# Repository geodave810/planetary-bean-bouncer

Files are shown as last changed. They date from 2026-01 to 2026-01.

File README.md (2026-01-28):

# Planetary Bean Bouncer

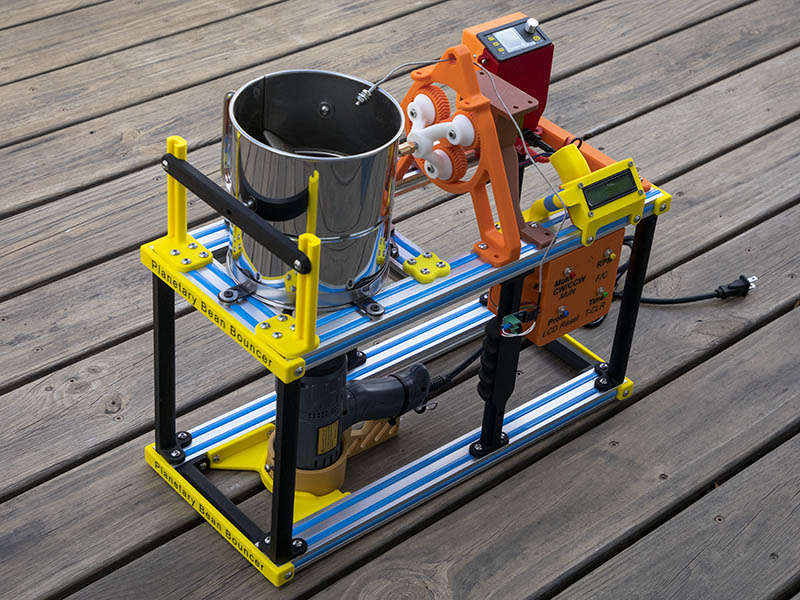
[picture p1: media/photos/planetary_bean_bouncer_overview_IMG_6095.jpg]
Planetary Bean Bouncer overview


Open-source DIY coffee roaster project based on an 8-cup flour sifter with a
stationary heat gun and a rotating agitator, controlled by Arduino-based firmware.

> ⚠️ **Safety notice:** This project involves high heat, mains power, and moving
mechanical parts. Read `DISCLAIMER.md` before building or operating.

## Overview

The Planetary Bean Bouncer is a small-batch coffee roaster that uses a modified
flour sifter to agitate coffee beans while heat is applied from a fixed-position
heat gun. The design focuses on simplicity, accessibility, and repeatability
using commonly available components.

This repository contains the firmware, 3D-printable parts, and reference
documentation needed to build and experiment with the roaster.

## Features
- Rotating agitator driven by a stepper motor
- Stationary heat gun (no linear motion in this design)
- Arduino-based controller
- Button and LCD user interface
- Temperature sensing support (thermocouple or thermistor, depending on build)
- Configurable parameters in firmware (speed, timing, alerts)

## Project status

This project is in active development. Documentation is currently minimal
and will be expanded over time as the design evolves.

## Repository layout
- `firmware/` — Arduino firmware (MIT License)
- `hardware/` — STL files and hardware reference images (CC BY-NC 4.0)
- `wiring/` — Basic UI wiring reference (Fritzing)
- `media/` — Photos and videos

## Fit & Tolerance Test Prints

Two optional test STLs are included to verify printer tolerances before printing any main parts:

- **hardware/STL/accessories/Test_1.stl** – Verifies screw, nut, bearing, and lever-lock electrical terminal fits.
- **hardware/STL/accessories/Gearing_5_1_16_24_64_Test_Rev36.stl** – A reduced-size planetary gear set using the same tolerances as the full gearbox, intended to check gear mesh and rotation (also works as a fidget).

Highly recommended if your printer or filament is untested.

See `docs/tolerance-test-prints.md` for details.

## Quick start
1. Review `hardware/README.md` for printed parts and notes
2. Review `wiring/README.md` for the basic UI wiring reference
3. Install the Arduino IDE
4. Open the firmware sketch in `firmware/`
5. Configure pins and parameters at the top of the sketch as needed
6. Upload to the Arduino and test without heat before roasting

## Hardware overview
- Controller: Arduino Uno (or compatible)
- Stepper driver: DRV8825, TMC2209, or similar (builder’s choice)
- Motor: NEMA 17 stepper motor
- Sensor: Thermocouple module (e.g., MAX6675) or thermistor
- Heat source: Consumer heat gun (stationary)

> Motor and driver wiring is intentionally not prescribed, as there are many
valid configurations depending on hardware choices.

For builders interested in fabricating their own wobble disc rather than purchasing one, a detailed fabrication guide that inspired this approach is available here:

https://library.sweetmarias.com/wp-content/uploads/2024/09/Wobble-Disc-Coffee-Roaster-3-red-tubes-model-build-instructions.pdf

## Licensing

This project uses multiple licenses:

- **Firmware:** MIT License  
- **Hardware design files (STL, images, diagrams):**
  Creative Commons Attribution-NonCommercial 4.0 (CC BY-NC 4.0)

This allows free personal and educational use while preventing unauthorized
commercial exploitation of the hardware design.

## Support this project ☕

This project is released as open source and free to use.

If you find it useful and would like to support continued development,
documentation, and future improvements, you can:

☕ **Buy me a coffee:** https://buymeacoffee.com/geodave

Support is entirely optional, but always appreciated.

## Credits

Project design and implementation: **David Bunch**  
Firmware was developed with AI-assisted code generation and subsequently
reviewed, tested, and maintained by the author.

Some components are derived from existing open-source designs and are credited
in the relevant subdirectories.

## Build log and videos

This project has been developed and documented over time through both
videos and a long-running build log.

### YouTube playlist
A playlist documenting the design, prototyping, testing, and iterations
of the Planetary Bean Bouncer:

https://www.youtube.com/playlist?list=PLyy5iFdDEfauqgzqg_eptvup8FIkFzkNk

New videos will be added as the project continues to evolve.

### Build log
A detailed build log and discussion thread dating back to September 2025,
including design decisions, experiments, and lessons learned:

https://forum.v1e.com/t/diy-coffee-roaster/51195

These resources provide additional context beyond what is captured
in the repository files.

## Build guide

A step-by-step mechanical build guide is available in the `docs/` directory.
This guide covers frame construction, drive components, and flour sifter
integration.

Electronics integration will be documented separately.

## FAQ

Common questions about build difficulty, food safety, and project scope are answered here:

➡️ [docs/FAQ.md](docs/FAQ.md)

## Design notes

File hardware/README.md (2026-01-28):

# Hardware Design Files

This directory contains hardware design files for the
**Planetary Bean Bouncer Coffee Roaster**, including STL files,
reference images, and diagrams.

## Licensing

The hardware design files in this directory are licensed under:

**Creative Commons Attribution–NonCommercial 4.0 International (CC BY-NC 4.0)**  
https://creativecommons.org/licenses/by-nc/4.0/

This license allows free personal and educational use of the hardware
design while preventing unauthorized commercial exploitation.

> Note: Firmware in this repository is licensed separately under the
> MIT License. See the top-level LICENSE files for details.

## Commercial use

If you are interested in using this hardware design for commercial
purposes (kits, products, or resale), please contact the author to
discuss licensing options.

Reasonable commercial licensing helps support continued development
of this project.

## Credits and Attribution

### Planetary Gear System

The planetary gear system used in this project is based on the following
open-source design:

- **Planetary Gear Set** by *Emmett Lalish*  
- Source: https://www.thingiverse.com/thing:53451  
- License: As specified by the original author on Thingiverse

The original design has been modified for this project, including
changes to dimensions, tolerances, and integration with the
Planetary Bean Bouncer assembly.

All original licensing terms of the upstream design are respected.

See /docs/tolerance-test-prints.md for optional test prints.

## Bill of Materials (BOM)

A bill of materials is provided in the `BOM/` directory as an Excel
spreadsheet:

- `Planetary_Bean_Bouncer_BOM.xlsx`

The BOM reflects the author’s current build and may include specific
part selections or suppliers. Equivalent components may be substituted
based on availability.

The BOM and other documentation in this directory are licensed under
CC BY-NC 4.0 unless otherwise noted.

## Cost and sourcing notes

The estimated total cost for the author’s build is approximately **$234 USD**.
This reflects the specific parts used and prices at the time of purchase.

Many builders may already have some components on hand (such as fasteners,
electronics, or motors), which can significantly reduce the total cost.

Several parts may also be substituted or fabricated by the builder. For example:
- The wobble disc can be machined or cut from suitable material instead of
  being purchased as a finished part.
- Equivalent motors, drivers, and fasteners may be used depending on availability.

As with most DIY projects, actual cost will vary based on sourcing,
substitutions, and existing inventory.

### Fabricating Your Own Wobble Disc

For builders interested in fabricating their own wobble disc rather than purchasing one, a detailed fabrication guide that inspired this approach is available here:

- **Wobble Disc Fabrication Guide**  
  https://library.sweetmarias.com/wp-content/uploads/2024/09/Wobble-Disc-Coffee-Roaster-3-red-tubes-model-build-instructions.pdf

This guide includes:
- Measurements
- Recommended materials
- Assembly considerations

Using this reference, builders can reduce part cost and customize the wobble disc to their own preferences. Always ensure proper balance and clearances when fabricating your own part.

For build history and videos, see the main README.

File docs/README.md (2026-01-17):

# Documentation

This directory contains documentation for the Planetary Bean Bouncer project.

## Available guides

- **Mechanical Build Guide**  
  Located in `build-guide/`  
  Covers frame construction, drive components, and flour sifter integration.

Electronics wiring and configuration are not yet documented and will be
addressed in a future update.

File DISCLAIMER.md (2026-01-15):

# Disclaimer

This project is provided for **educational and experimental purposes only**.

Building and operating a DIY coffee roaster involves inherent risks, including
but not limited to:

- High temperatures and risk of burns or fire
- Use of mains-powered electrical equipment
- Moving mechanical components and pinch points
- Smoke, fumes, and the need for adequate ventilation

## Responsibility

You are solely responsible for:

- The safe design, construction, wiring, and operation of your build
- Selecting materials and components appropriate for heat and food-contact use
- Compliance with applicable electrical codes, safety standards, and local laws
- Supervising the device during operation (do not leave unattended)

The author does not guarantee the safety, performance, or suitability of any
design, instructions, or files provided in this repository.

## No warranty

All files, designs, and documentation are provided **“as is”**, without warranty
of any kind, express or implied.

See the applicable license files for additional terms and limitations.

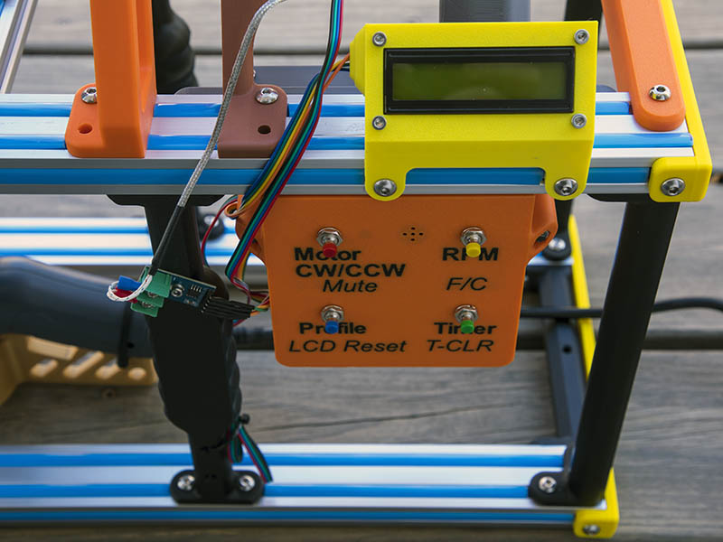
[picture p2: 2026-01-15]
media/photos/controller_closeup_IMG_6003.jpg

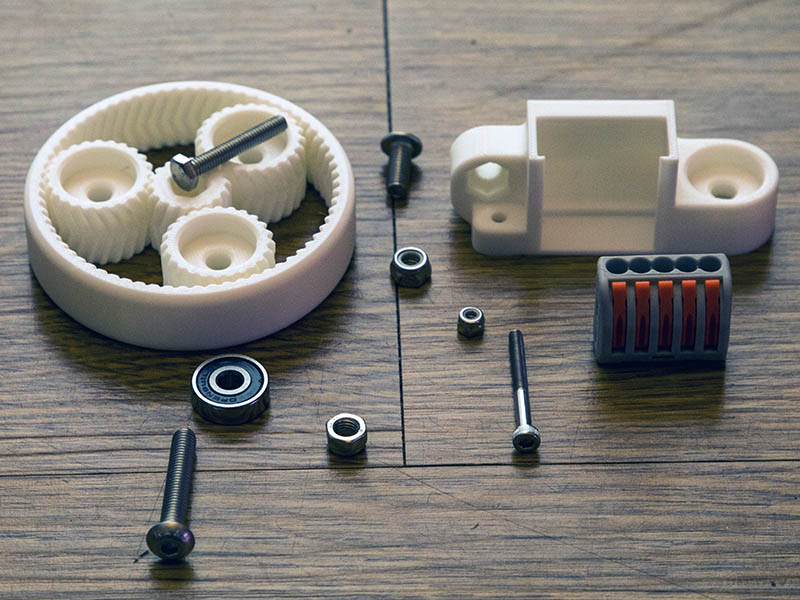
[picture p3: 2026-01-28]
media/photos/IMG_6096_800x600.jpg

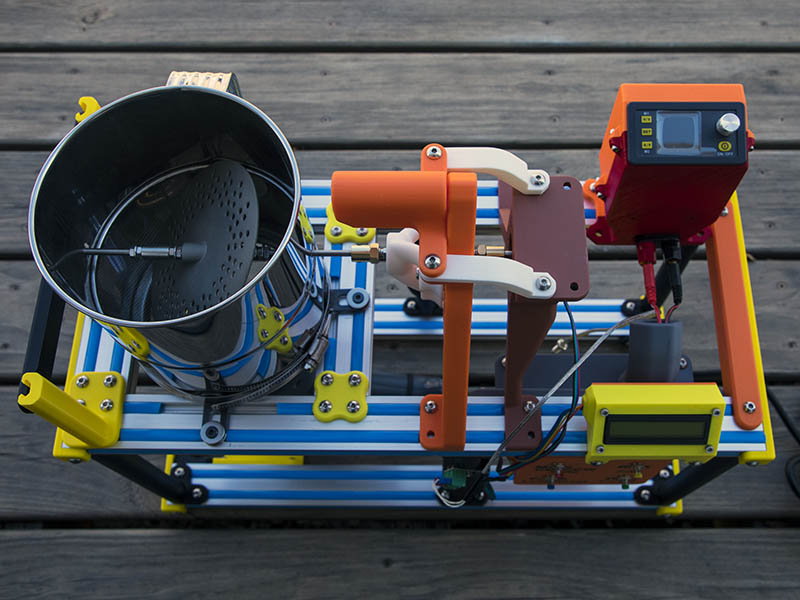
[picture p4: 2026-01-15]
media/photos/overall_top_IMG_6002.jpg

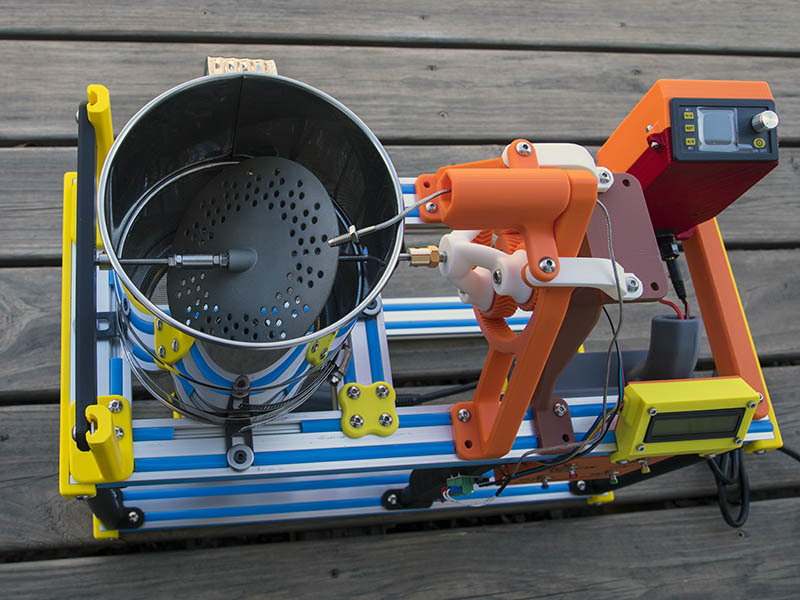
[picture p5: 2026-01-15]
media/photos/agitator_detail_IMG_6001.jpg

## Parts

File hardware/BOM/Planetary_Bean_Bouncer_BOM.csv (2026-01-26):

Planetary Bean Bouncer BOM | QTY | Item | Notes | Optional / Fabrication Notes | Unit Price | Extended Price | Link
 | 1 | Heat Gun |  |  | $28.99 | $28.99 | https://www.amazon.com/dp/B07DX4PL1M?ref=ppx_yo2ov_dt_b_fed_asin_title
 | 1 | 8 Cup SS Flour Sifter |  |  | $23.99 | $23.99 | https://www.amazon.com/dp/B0DD3ZB6MT?th=1
 | 4 | 2040 V-Groove 500mm (You could also use T-Slot) |  |  | $10.08 | $40.32 | https://www.zyltech.com/2040-v-groove-extrusion-pre-cut-lengths-300mm-2000mm/
 | 1 | 2040 V-Groove 300mm (You could also use T-Slot) |  |  | $6.95 | $6.95 | https://www.zyltech.com/2040-v-groove-extrusion-pre-cut-lengths-300mm-2000mm/
 | 1 | Flexible Rubber Extrusion Strips (10 meters) | Keeps most of Chaff from roasting out of extrusions |  | $11.95 | $11.95 | https://www.zyltech.com/flexible-rubber-extrusion-strips-for-20mm-aluminum-extrustion-black-blue-or-white/
 | 1 | 5"-7" SS Band Clamp |  |  | $3.99 | $3.99 | I bought mine from ACE hardware, too expensive from Amazon
 | 1 | 24 - 18x18x30 L Brackets (4 needed) |  |  | $7.99 | $7.99 | https://www.amazon.com/dp/B09G9GKFPT?th=1
 | 1 | M5 fender washers (pack of 50) only 12 needed |  |  | $7.99 | $7.99 | https://www.amazon.com/dp/B0CLK7J4NB?th=1
 | 4 | M3x25mm (LCD Case) |  |  | $0.12 | $0.48 | https://boltdepot.com/Product-Details?product=15291
 | 8 | M3x10mm (Arduino Mount and Motor Mount) |  |  | $0.08 | $0.64 | https://boltdepot.com/Product-Details?product=7220
 | 8 | M3 Locknuts (Not needed on Motor Mount) |  |  | $0.07 | $0.56 | https://boltdepot.com/Product-Details?product=4792
 | 1 | M5x12mm screws about 72 needed (Pack of 100) |  |  | $8.60 | $8.60 | https://boltdepot.com/Product-Details?product=6633
 | 1 | M5 Tee Nuts about 72 needed(Pack of 100) |  |  | $7.95 | $7.95 | https://www.amazon.com/Kangsiyu-Aluminum-Profile-Printer-Accessory/dp/B0FQ3P1GF3/141-9617972-1494545
 | 3 | M5x35mm screws (Planets to Planet carrier) |  |  | $0.32 | $0.96 | https://boltdepot.com/Product-Details?product=6638
 | 1 | 625-2RS bearings (12 pack) (planet bearings only 7 needed) |  | 1 bearing end of shaft rides on. | $8.99 | $8.99 | https://www.amazon.com/%EF%BC%BB12-Pack%EF%BC%BD625-2RS-Ball-Bearings-Miniature/dp/B0BRQP2QG7?th=1
 | 3 | M5 washers (planet bearings) | The washers I used were precision washers |  | $0.05 | $0.15 | https://boltdepot.com/Product-Details?product=4515
 |  |  | from openbuilds if you can find them
 | 8 | M5 locknuts |  |  | $0.09 | $0.72 | https://boltdepot.com/Product-Details?product=4794
 | 3 | M5x50mm screws for controller case |  |  | $0.56 | $1.68 | https://boltdepot.com/Product-Details?product=6641
Electrical Parts |  |  |  |  |  |  |  | Parts for optional 3D printed wobble disc |  |  |  |  |  |  | Parts for optional 3D printed wobble disc |  |  |  |  |  |  | Parts for optional 3D printed wobble disc |  |  |  |  |  |  | Parts for optional 3D printed wobble disc |  |  |  |  |  |  | Parts for optional 3D printed wobble disc |  |  |  |  |  |  | Parts for optional 3D printed wobble disc |  |  |  |  |  |  | Parts for optional 3D printed wobble disc
 | QTY | Item | Notes |  | Unit Price | Extended Price | Link |  | QTY | Item | Notes | Unit Price | Extended Price | Link |  | QTY | Item | Notes | Unit Price | Extended Price | Link |  | QTY | Item | Notes | Unit Price | Extended Price | Link |  | QTY | Item | Notes | Unit Price | Extended Price | Link |  | QTY | Item | Notes | Unit Price | Extended Price | Link |  | QTY | Item | Notes | Unit Price | Extended Price | Link |  | QTY | Item | Notes
 | 1 | 1602 LCD Display with Backpack | I did not purchase this one, but should work as well as what I bought | If you want solid electrical connections, you should be familiar | $8.99 | $8.99 | https://www.amazon.com/dp/B0D2L9SK1P?th=1
 | 1 | 0.9 Step Angle Nema 17 Stepper Motor 1.5 A |  | with soldering and solder some of these connections. | $12.95 | $12.95 | https://www.zyltech.com/high-accuracy-0-9-step-angle-nema-17-stepper-motor-1-5-a-0-42-nm-59-ozin/
 | 1 | MAX6675 Thermocouple | I did not purchase this one, but should work as well as what I bought | So you will need some extra supplies here | $7.69 | $7.69 | https://www.amazon.com/HiLetgo-MAX6675-Thermocouple-Temperature-Arduino/dp/B01HT871SO?th=1
 | 1 | Arduino Uno + CNC shield + DRV8825 | I did not purchase this one, but should work as well as what I bought |  | $18.99 | $18.99 | https://www.amazon.com/DAOKI-Expansion-Arduino-Heatsink-Engraving/dp/B08KFYKKN4
 | 1 | 12V Power Supply 5A 60W | I did not purchase this one, but should work as well as what I bought |  | $11.89 | $11.89 | https://www.amazon.com/ALITOVE-100-240V-Transfomer-Converter-5-5x2-5mm/dp/B0F1N4J7R2?th=1
Parts for optional 3D printed wobble disc
 | QTY | Item | Notes |  | Unit Price | Extended Price | Link
 | 1 | 3D printed 316L Wobble Disc |  | See Sweet Maria?s wobble disc fabrication guide (link in README). | $55 | $55.00 | Best price I found was from https://app.prototi.com/quote
 | 1 | 4 Pcs M5x200mm 304 SS Threaded Rod (only 1 needed) |  |  | $7.99 | $7.99 | https://www.amazon.com/dp/B09LGXG6F1?th=1
 | 2 | M5 External tooth SS washers |  |  | $0.06 | $0.12 | https://boltdepot.com/Product-Details?product=7121
 | 4 | M5 serrated flange nuts SS |  |  | $0.22 | $0.88 | https://boltdepot.com/Product-Details?product=12008
 | 4 | M5 Hex Nuts (Use 4mm wide nuts, NOT narrow jam nut) | Narrow jam nuts make it more difficult to get wrench on |  | $0.07 | $0.28 | https://boltdepot.com/Product-Details?product=4775
 |  |  | both nuts
 | 1 | M5x18mm long SS spacers | Not completely necessary but covers more of threaded rod |  | $9.69 | $9.69 | https://www.amazon.com/dp/B0F8QPGNJL?
 | 1 | 10 pack of 5mm Bore shaft lock collars SS (only 1 needed) | These do not have to be SS since they are outside sifter |  | $7.88 | $7.88 | https://www.amazon.com/dp/B0F5TFX6PL?th=1
 | 1 | 5mm bore motor hex coupler, M4 threads on opposite side | Connects Motor to Sun gear and planets to main shaft |  | $7.99 | $7.99 | https://www.amazon.com/dp/B08M379TCT?th=1
 | 2 | M4 x25mm SS tap bolts | These connect planetary gear to M4 bore of hex couple on |  | $0.19 | $0.38 | https://boltdepot.com/Product-Details?product=5940
 |  |  | each side of the gear.
 |  |  | you might want to get a couple of 20mm & 30mm length
 |  |  | in case those lengths work better for you.
 | 2 | M4 Locknut SS |  |  | $0.08 | $0.16 | https://boltdepot.com/Product-Details?product=4793
 | 2 | M4 Lock washers SS |  |  | $0.07 | $0.14 | https://boltdepot.com/Product-Details?product=4811
 |  | Estimated total (author?s build): |  |  |  | $313.92
 |  | Prices are approximate and reflect the author?s build at the time of writing.
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

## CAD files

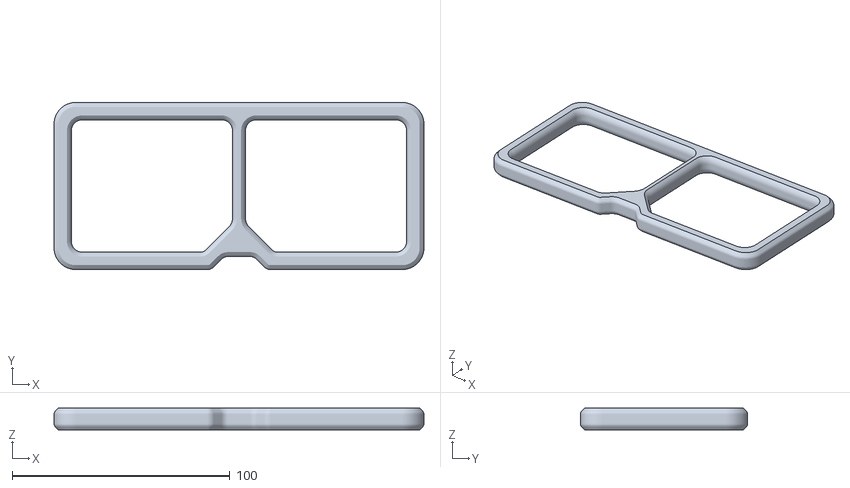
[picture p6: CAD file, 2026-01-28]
hardware/STL/accessories/Bearing_Height_Shim.stl
170.0 x 76.8 x 10.0

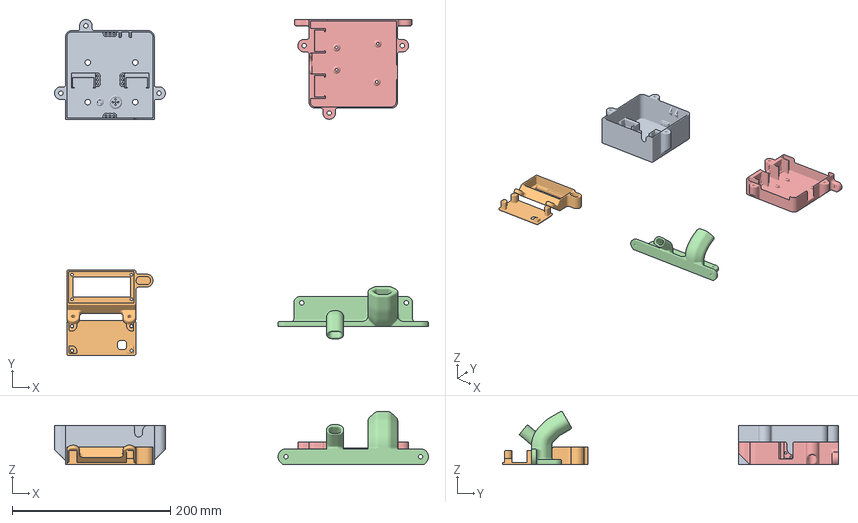
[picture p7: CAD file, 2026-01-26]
hardware/STL/electronics/ArduioUnoMount_Rev4.3mf
472.2 x 424.2 x 67.3 mm
ArduioUnoTopMount_Rev4.stl_1
LCD1602_MinCase.stl
Text
ShortV_Connect_V3.stl
ArduioUnoBaseMount_Rev4_1.stl

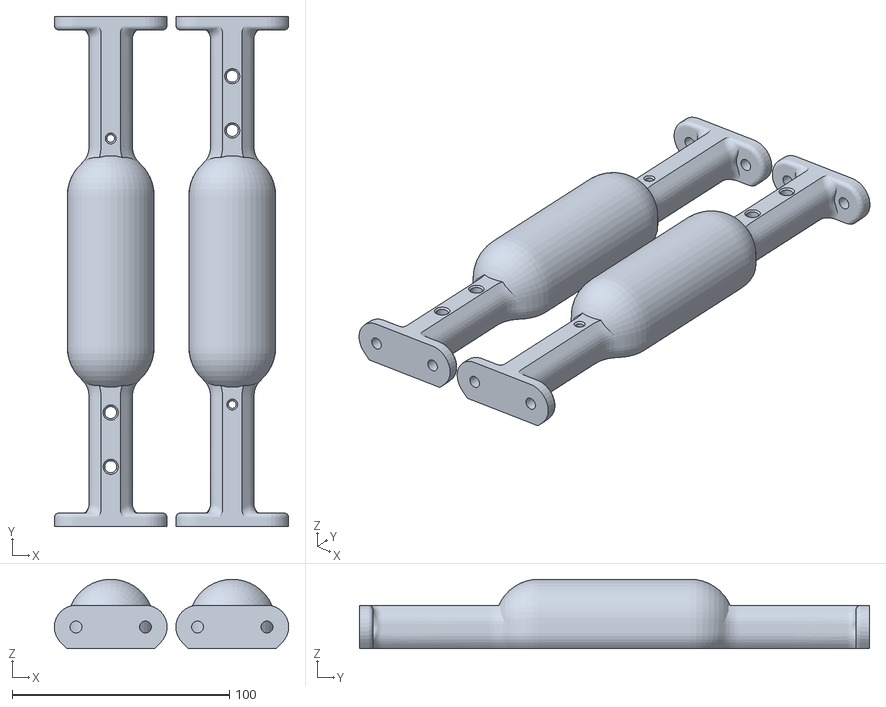
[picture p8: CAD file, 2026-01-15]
hardware/STL/frame/CenterColumns.stl
108.0 x 235.0 x 32.0

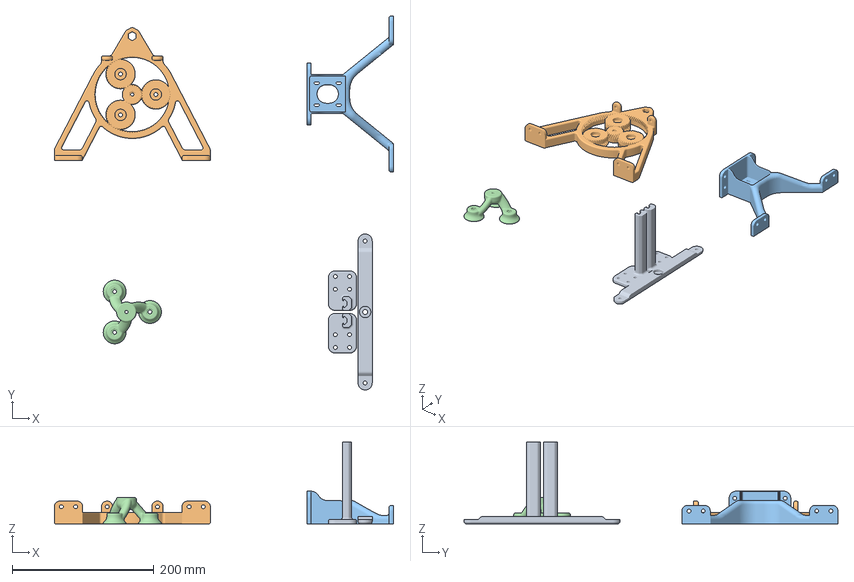
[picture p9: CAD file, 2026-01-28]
hardware/STL/gearing/PlanetaryBeanBouncerDriveTrain.3mf
478.5 x 527.2 x 115.0 mm
BearingColumns.stl
FlourPlanetGears_5_1_24_36_96_Rev35.stl
Nema17_Medium_Mount.stl
PlanetDrive_5_1_Rev35.stl

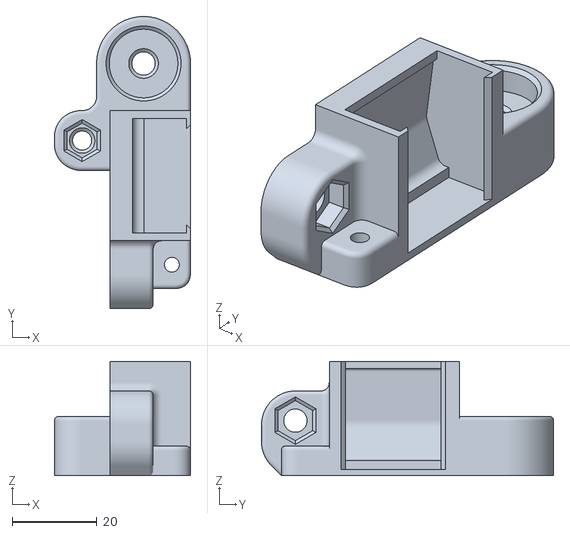
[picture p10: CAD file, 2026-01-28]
hardware/STL/accessories/Test_1.stl
32.1 x 69.0 x 27.0

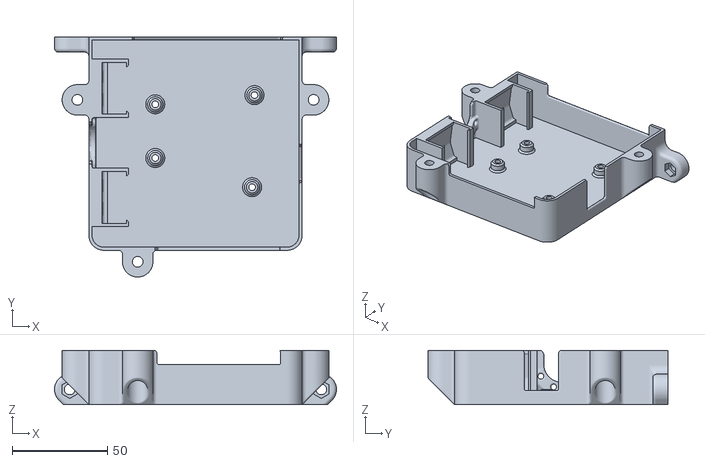
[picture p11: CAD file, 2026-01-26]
hardware/STL/electronics/ArduioUnoBaseMount_Rev4_1.stl
148.0 x 126.0 x 28.5

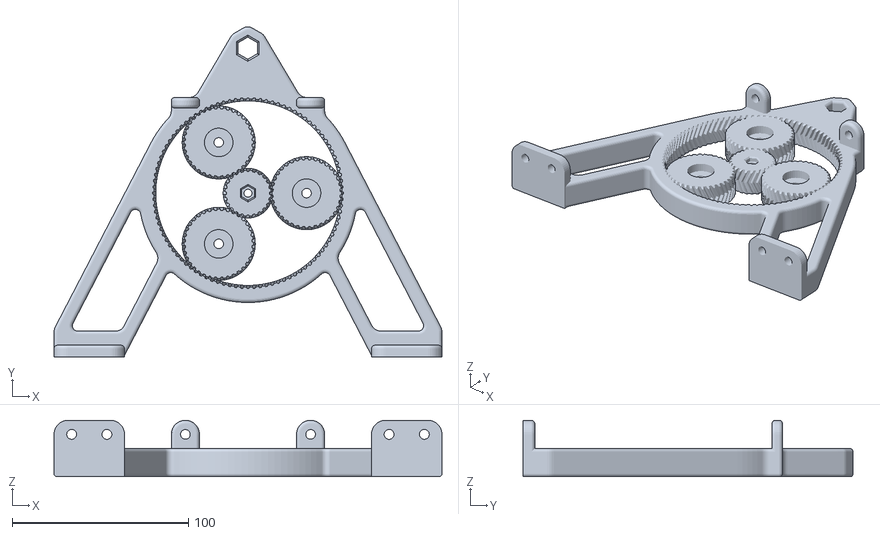
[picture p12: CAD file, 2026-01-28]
hardware/STL/gearing/FlourPlanetGears_5_1_24_36_96_Rev35.stl
220.0 x 187.3 x 32.0

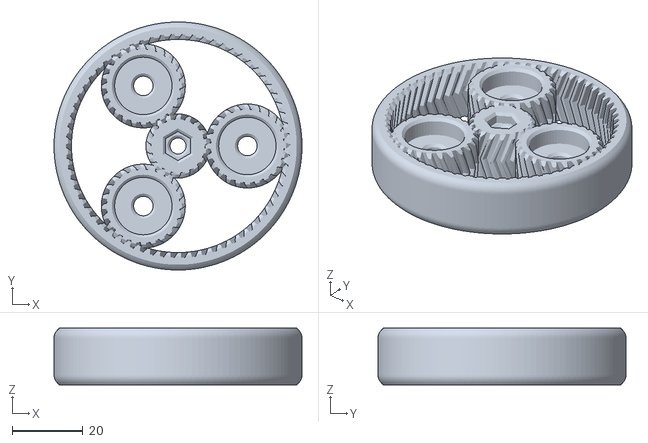
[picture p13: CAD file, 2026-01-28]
hardware/STL/accessories/Gearing_5_1_16_24_64_Test_Rev36.stl
70.0 x 70.0 x 16.0

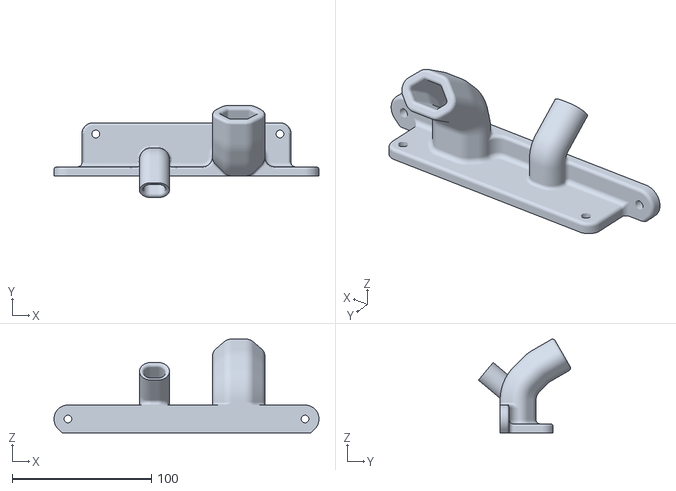
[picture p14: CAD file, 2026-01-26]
hardware/STL/electronics/ShortV_Connect_V3.stl
190.0 x 66.1 x 67.3

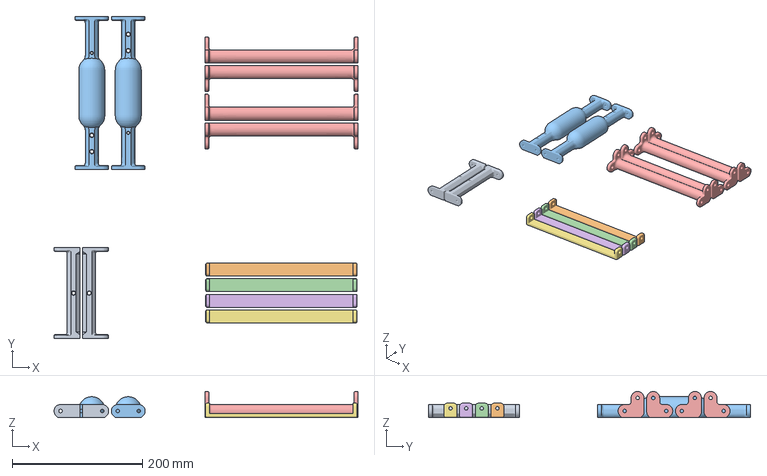
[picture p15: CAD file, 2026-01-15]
hardware/STL/frame/AluminumFrame_Parts.3mf
466.7 x 494.7 x 39.9 mm
Assembly x 7

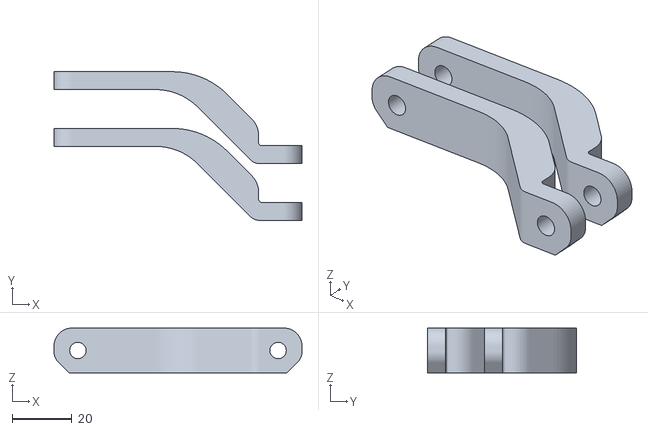
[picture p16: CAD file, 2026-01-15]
hardware/STL/gearing/Motor_TieBraces.stl
83.0 x 49.8 x 15.0

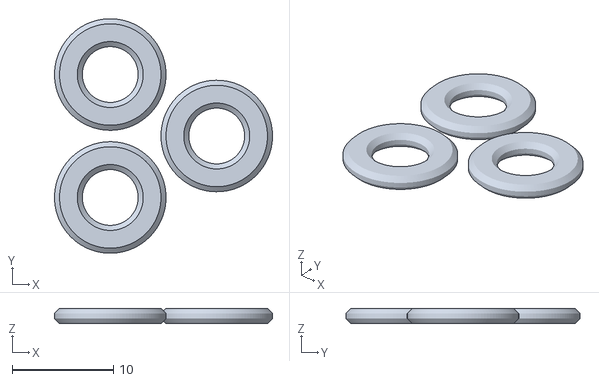
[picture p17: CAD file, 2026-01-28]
hardware/STL/accessories/M5_Bearing_Shims.stl
21.5 x 23.1 x 1.50

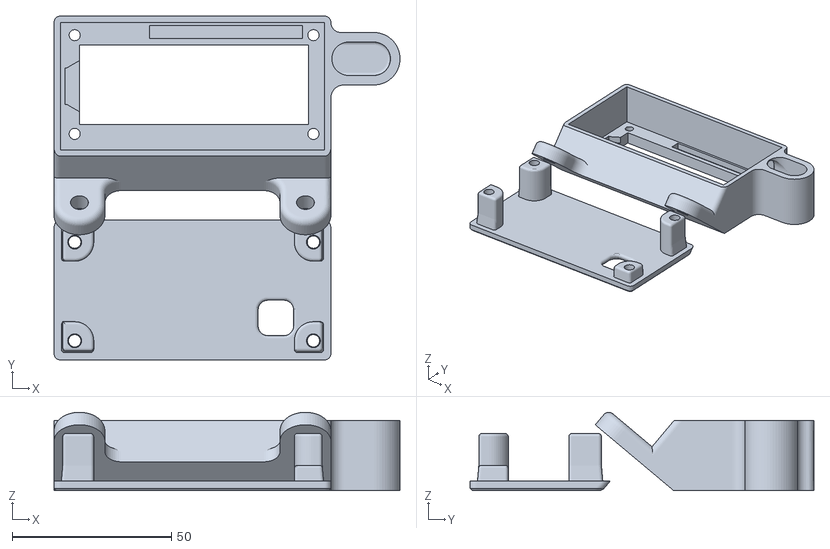
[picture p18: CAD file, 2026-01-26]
hardware/STL/electronics/LCD1602_MinCase.stl
108.7 x 108.0 x 24.7

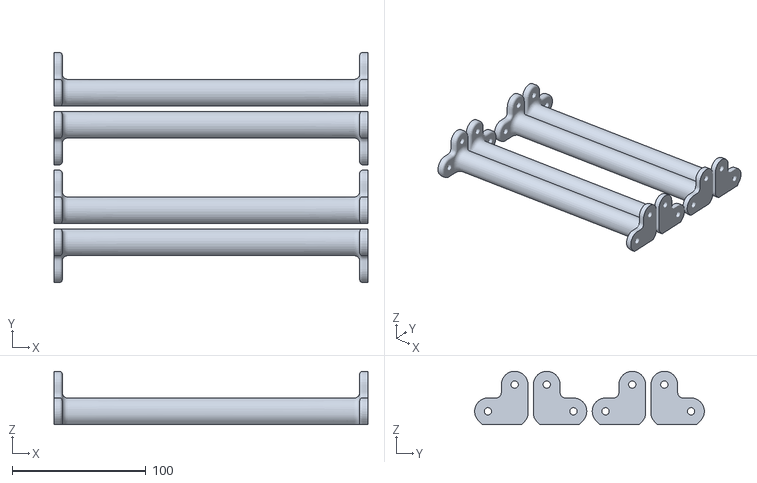
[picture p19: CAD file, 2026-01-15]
hardware/STL/frame/2020_CornerColumns.stl
235.0 x 172.0 x 39.9

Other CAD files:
hardware/STL/gearing/BearingColumns.stl
hardware/STL/accessories/HexAdapter_Height_Shim.stl
hardware/STL/electronics/HeatGunStand_42mm.stl
hardware/STL/gearing/Nema17_Medium_Mount.stl
hardware/STL/accessories/3D_Print_WobbleDisc_JambNuts.step
hardware/STL/accessories/ShaftCoupler_M5x20mm_M5x20mm_rev18.stl
hardware/STL/accessories/SifterDrillTemplate.stl
hardware/STL/accessories/SilfterOutsideDrillGuide.stl
hardware/STL/electronics/ArduioUnoTopMount_Rev4.stl
hardware/STL/frame/2020x140_Mod.stl
hardware/STL/frame/2020x2040_FarEndPlate.stl
hardware/STL/frame/2040_Bot_Connects.stl
hardware/STL/frame/2040x2040_End_Plates.stl
hardware/STL/frame/Endcap_2040s.3mf
hardware/STL/frame/Heatgun_Center_V2.stl
hardware/STL/gearing/PlanetDrive_5_1_Rev35.stl
hardware/STL/gearing/SensorChannel.stl

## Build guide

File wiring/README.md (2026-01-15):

# Wiring reference

This directory contains a simplified wiring reference for the
Planetary Bean Bouncer controller user interface.

## Included files

- `Planetary_Bean_Bouncer_UI.fzz`  
  Fritzing project file showing the breadboard layout.

- `Planetary_Bean_Bouncer_UI_bb.png`  
  PNG export of the breadboard view for easy viewing without Fritzing.

## Scope

The wiring diagram illustrates the following components:
- Arduino Uno
- LCD (I2C)
- Buttons
- Status LEDs
- Buzzer

Stepper motor and driver wiring is intentionally omitted, as there are
many valid configurations depending on the hardware used.

## Notes

Resistor values shown are typical; exact values are not critical.

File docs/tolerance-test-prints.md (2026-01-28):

# Fit & Tolerance Test Prints

These test prints are provided to validate printer accuracy, filament behavior, and hardware fit before printing the main Planetary Bean Bouncer parts.

## When to Use These
- New printer or newly tuned printer
- New filament brand or material
- If previous prints showed tight fits, binding, or gear noise

---

## Test_1.stl – Hardware Fit Test

**Purpose:**  
Validates all commonly used hardware fits in this project.

**Covers:**
- Screw and nut sizes used throughout the build
- Bearing fits
- Lever-lock electrical terminal fit

**How to Evaluate:**
- Screws should insert without excessive force
- Nuts should press in firmly without cracking
- Bearings should be snug but removable by hand
- Lever-lock terminal should slide in without distortion

If fits are too tight or loose, adjust:
- Horizontal expansion
- Flow rate
- Extrusion multiplier

---

## Gearing_5_1_16_24_64_Test_Rev36.stl – Planetary Gear Test

**Purpose:**  
A compact planetary gear set using the same tolerances as the full gearbox.

**Notes:**
- Functionally equivalent tolerances to the full-size gear system
- Can be assembled and rotated by hand
- Small enough for quick test prints
- Also doubles as a fidget after printing

**Pass Criteria:**
- Gears rotate smoothly by hand
- No binding or tooth fusion
- Minimal backlash consistent with printed gears

---

## Recommended Print Settings
(Use the same settings intended for the final parts)

- Layer height: ___
- Nozzle size: ___
- Material: ___
- Perimeters: ___

---

## If Tests Fail
- Do **not** force assemblies
- Adjust tolerances or slicer settings
- Reprint tests before printing final parts

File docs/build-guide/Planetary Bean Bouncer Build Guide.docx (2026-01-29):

Planetary Bean Bouncer – Mechanical Build Guide

Before you begin:

- Review the full guide once before assembling.

- Print Test_1.stl to verify hole tolerances for screws, nuts, and bearings.

- Print Gearing_5_1_16_24_64_Test_Rev36.stl to test planetary gear meshing (can be used as a fidget after printing).

- Verify you have all hardware listed in the BOM.

- Do not fully tighten fasteners until shaft alignment is confirmed.

This guide documents the mechanical assembly of the Planetary Bean Bouncer coffee roaster. Electronics wiring and configuration are not covered in this document and will be addressed in a separate guide.

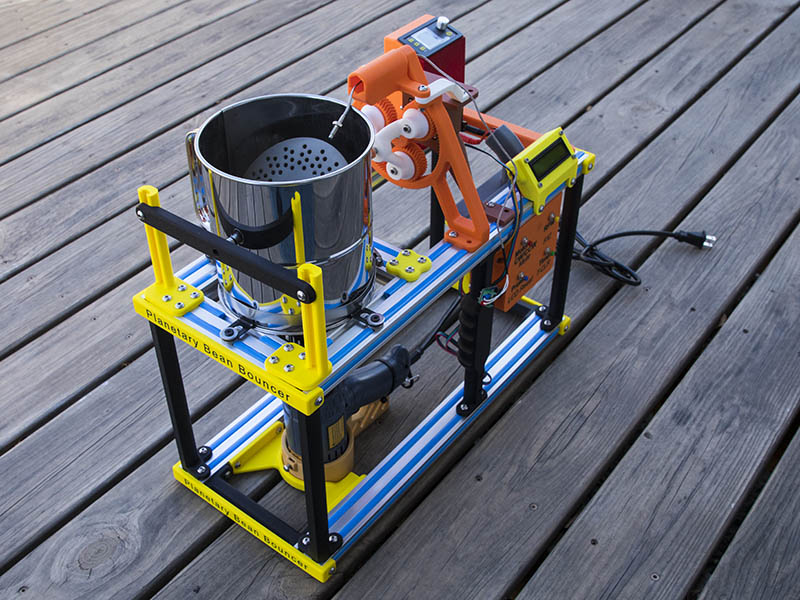
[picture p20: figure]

Frame

The aluminum extrusion part of the frame consists of 4-2040x500mm and 2-2040x140mm V-Slot extrusion. You should also be able to substitute T-Slot 2040 if you prefer, but I have not tested those. I am using 74 Tee Nuts and all the 3D printed parts are sized to use M5x12mm screws. I use 18-8 stainless steel button head screws as I prefer them. Anything outside the sifter does not need to be stainless though. You might have less or more of these Tee Nuts depending on how you configure it. For instance, you will probably power the 12 V supply for the motor differently than I do or you might not want to bother with the planetary gear system.

We will start with building the bottom frame. For the bottom frame we start by assembling V2040_Bot_Connect_1 (1st part of 2040_Bot_Connects.stl) and the Heatgun_Center_V2 3D prints. If you are using a different heat gun than in BOM, this probably will not work for you. The Heat gun center part is not necessary but makes it easy to line up the heat gun if you are using the same heat gun I have listed in BOM. You need 4-M5x12mm screws with Tee Nuts for the Heat gun center part and 2-M5x12mm screws with Tee Nuts for the V2040_Bot_Connect_1

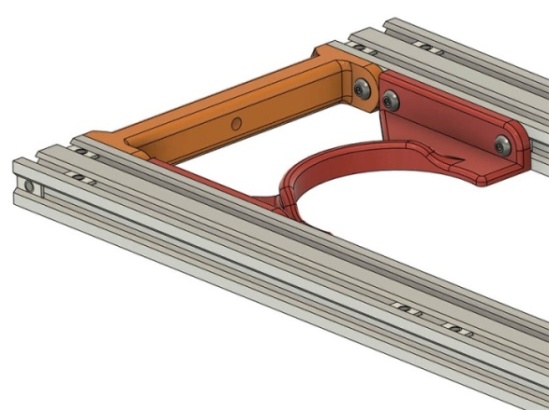
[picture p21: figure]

Connect V2040_Bot_Connect_2 (2nd part of 2040_Bot_Connects.stl) at each end of the frame with 2-M5x12mm screws and Tee Nuts like the other end.

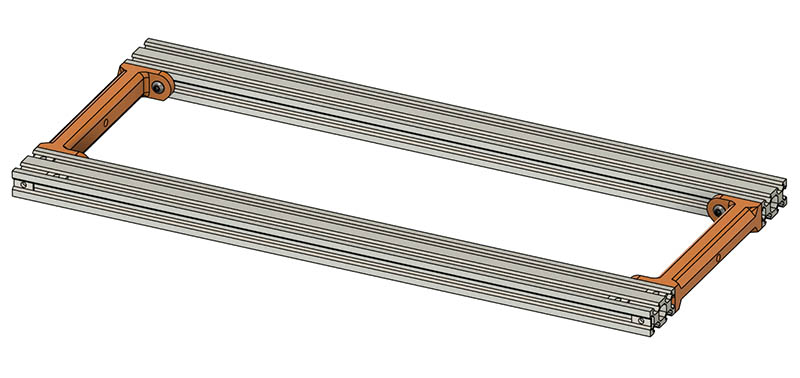
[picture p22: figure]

Add V2020_Column_1 (1st part of 2020_CornerColumns.stl) to the front corner below where sifter will be using 2-M5x12mm screws. These columns are slightly different because of print orientation, but essentially any of the 4 can go in any corner.

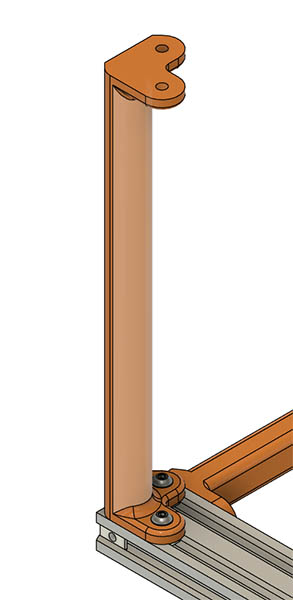
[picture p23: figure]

Add V2020_Column_2 (2nd part of 2020_CornerColumns.stl) to opposite short side using 2-M5x12mm screws.

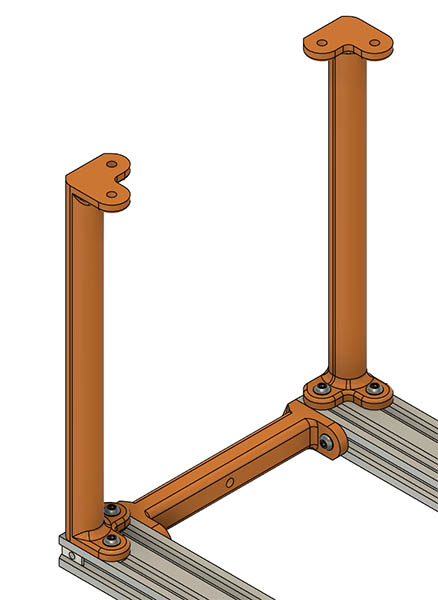
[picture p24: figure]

Do the same for the opposite side using 4-M5x12mm screws.

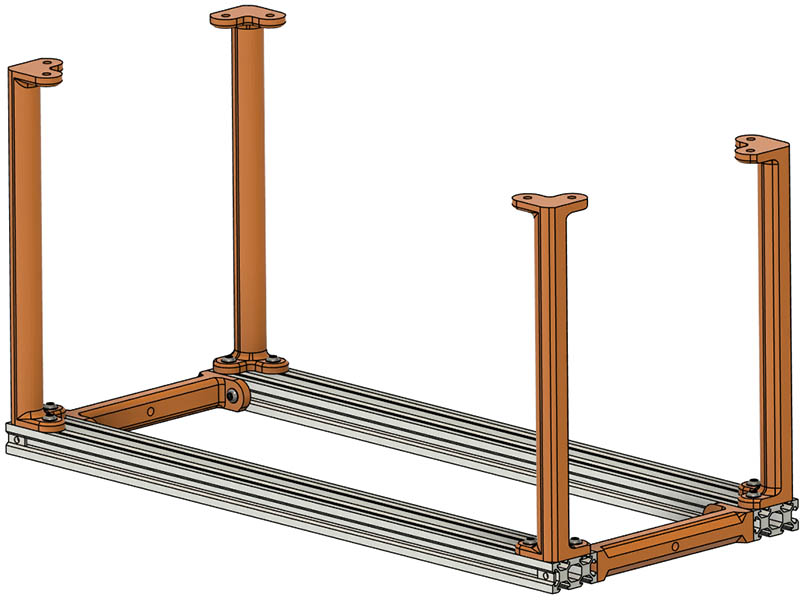
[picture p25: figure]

Assemble CenterColumn_1.stl and CenterColumn_2.stl to the bottom frame using a total of 4-M5x12mm screws as shown. They do not necessarily have to go in the middle. I have the back one in the middle for grabbing the center to dump roasted beans, but the front one I have closer to electronics to fasten MAX6675 and wire tie motor wire.

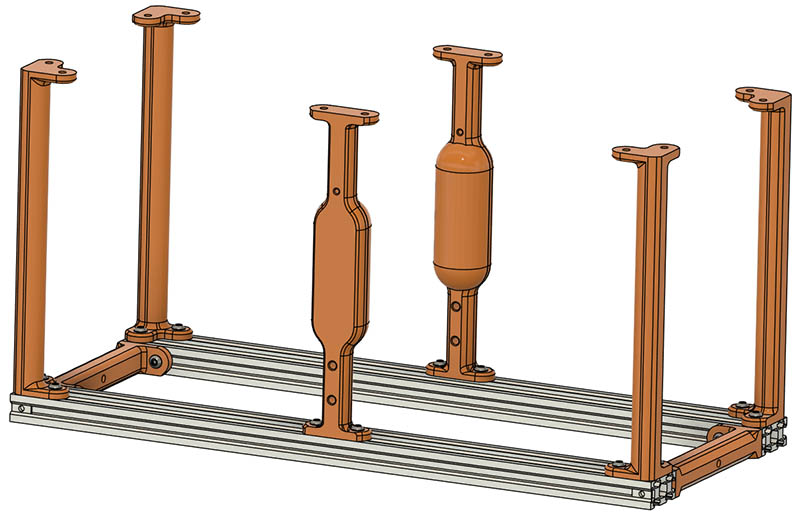
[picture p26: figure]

Turn the bottom frame upside down and assemble the 2-2040x500mm lengths to it using 12-M5x12mm screws with a Tee Nut for each screw.

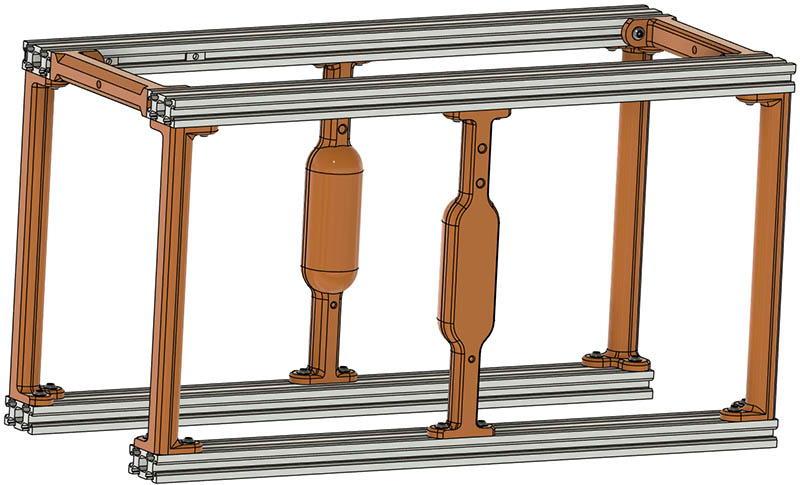
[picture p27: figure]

Turn frame right side up again and add 10 Tee Nuts as shown in green to the 2–2040x140mm length extrusions. They do not need to be positioned correctly yet.

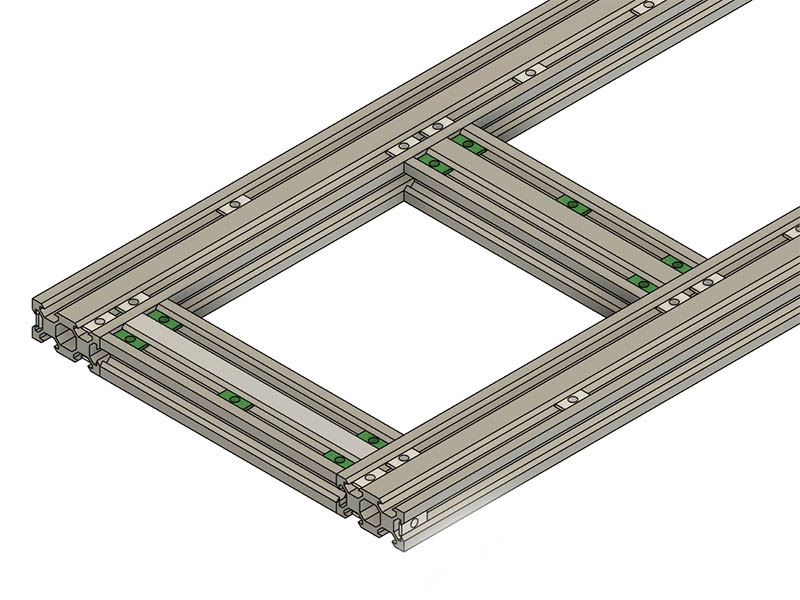
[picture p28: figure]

Attach Bearing_Column_1.stl and Bearing_Column_2.stl (from BearingColumns.stl ) to the end of the 2040x500mm top frames and the short 2040x140mm extrusion as shown. Make sure you have a Tee Nut as shown in the middle of short 2040. It does not have to be centered yet. Use 8-M5x12mm screws with Tee Nuts in the extrusions to connect these.

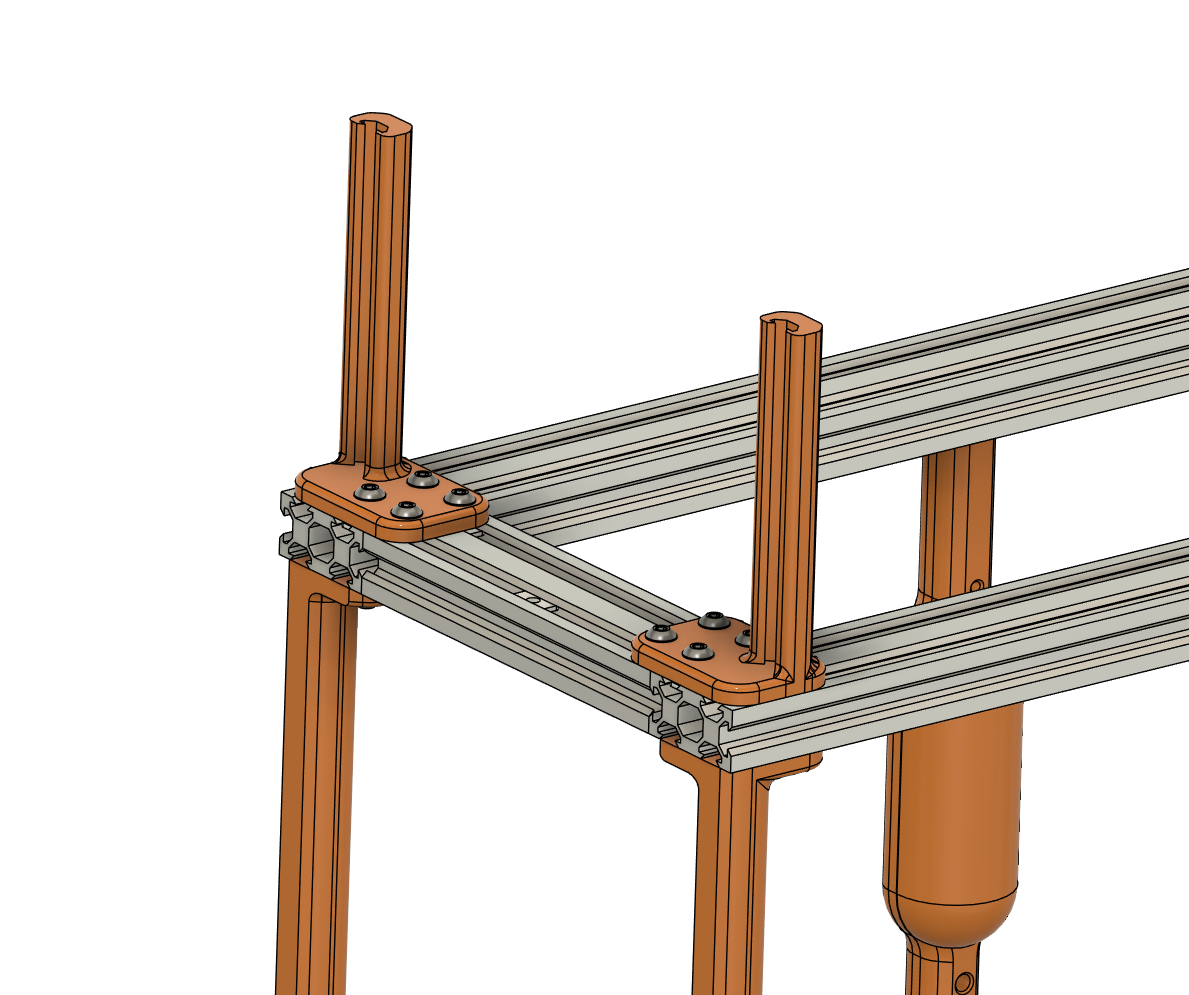
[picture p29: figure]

Take the BearingBar.stl (from BearingColumns.stl ) 3D print and insert a 625-2RS into it as shown here.

Use the Bearing_Height_Shim.stl to set the correct height for the Bearingbar as shown below.

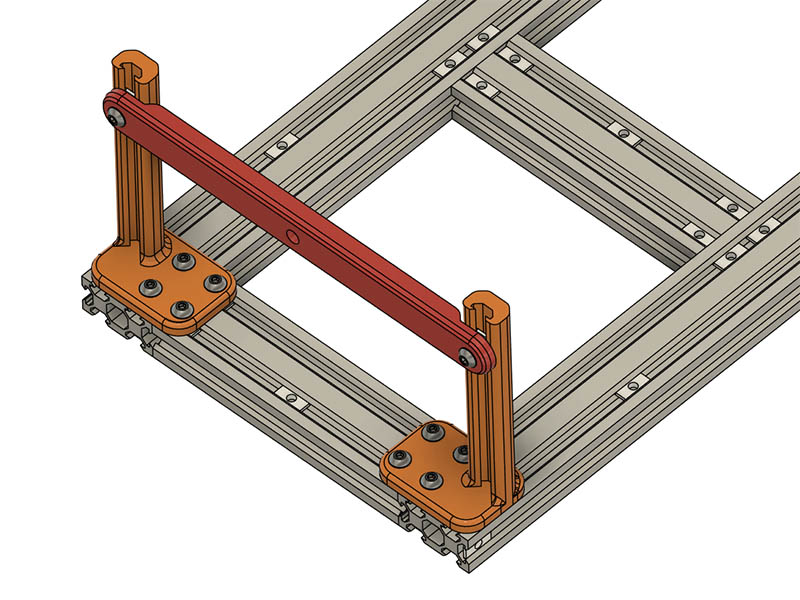
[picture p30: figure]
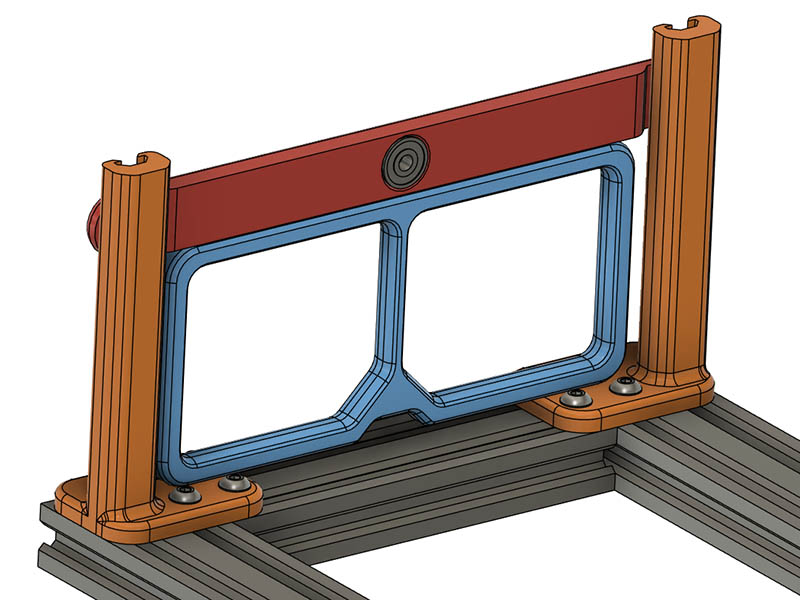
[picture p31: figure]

Assemble the 2 V2040x240_End_Plates.stl to the other short 2040x140mm extrusion with 8-M5x12mm screws and Tee Nuts. Make sure you have a Tee Nut in the extrusion as we did in the other short 2040x140mm. Make sure it is in the correct groove as shown.

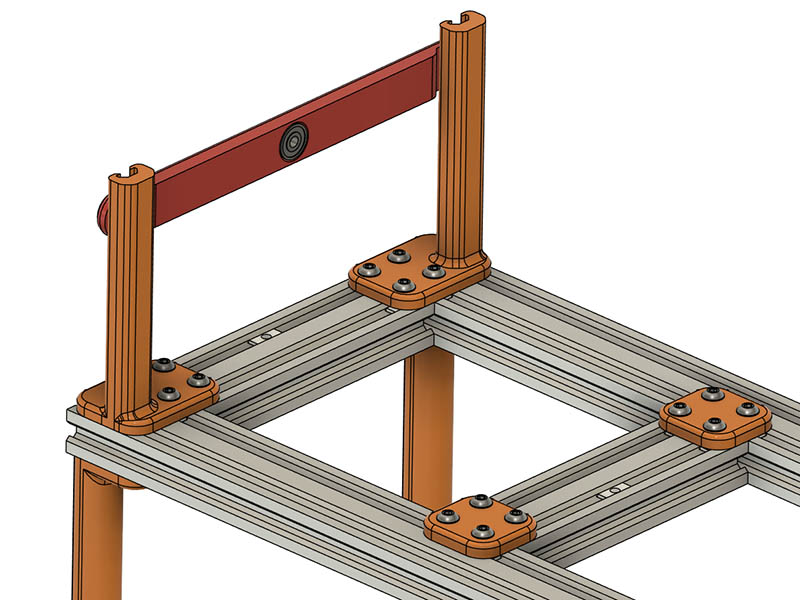
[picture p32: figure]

Add the ShortV_Connect_V3.stl before putting the end piece on. This is used for connecting the Electronics case to the extrusion. If you are putting together the Arduino UNO case I made, you may want to attach the case and LCD case to this before attaching to the 2040 extrusion.

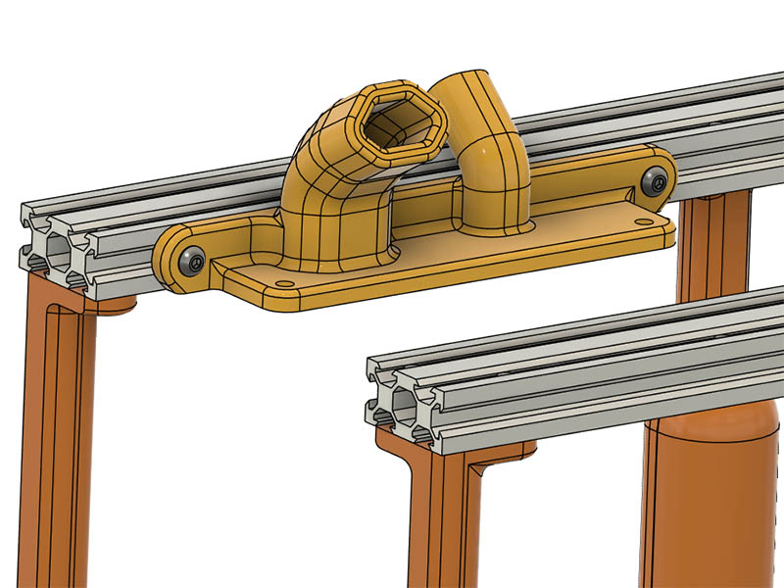
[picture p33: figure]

The next part to install is the V2020x140_Mod.stl 3D print. You could also use a 2020x140mm length of extrusion, but this uses only 1 Tee Nut on each side and you do not have any grooves for chaff to get in.

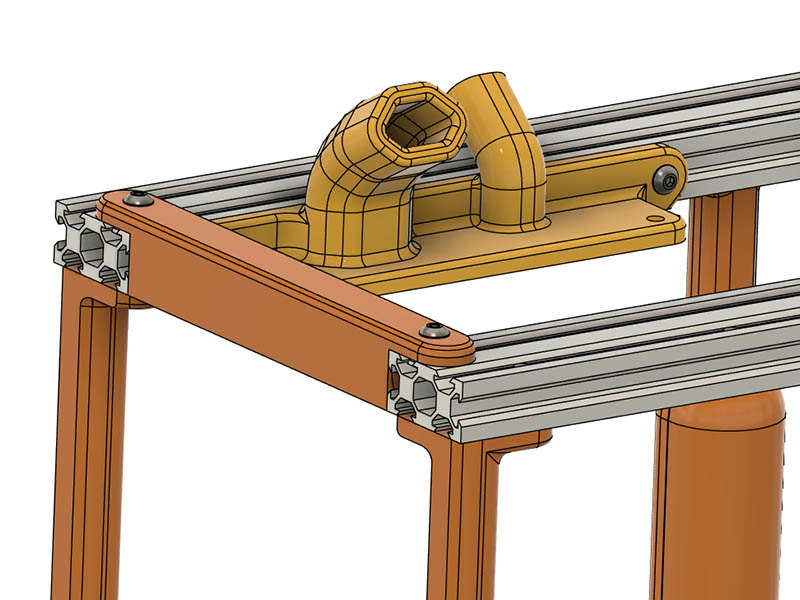
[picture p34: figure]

Except for putting the end caps on this completes the top frame construction. I would not put them on until the end in case you need to insert some Tee Nuts somewhere you missed. Only the 2 Tee Nuts in the short 2040x140mm extrusion need to be in there at this point. The others are easy to put in when you need them until the endcaps go on.

Optional 5:1 Planetary Gear

Below is an exploded view of the planetary gear system. I am only showing the hardware for 1 planet to simplify the view.

Hardware:

Planet connection hardware:

3 – M5x30mm button head screws

6 - 625-2RS bearings

3 – M5 Shim washers (flat washers will probably also work)

3 – M5 Locknuts

Shaft Connection hardware:

2 – M4x25mm Tap Bolts

2 – M4 Lock washers

2 – M4 Locknuts

2 – Brass Hex Coupler 5mm bore and M4 threads on Hex end

2040 Connection hardware:

2 – M5x12mm screws

2 – M5 Tee Nuts

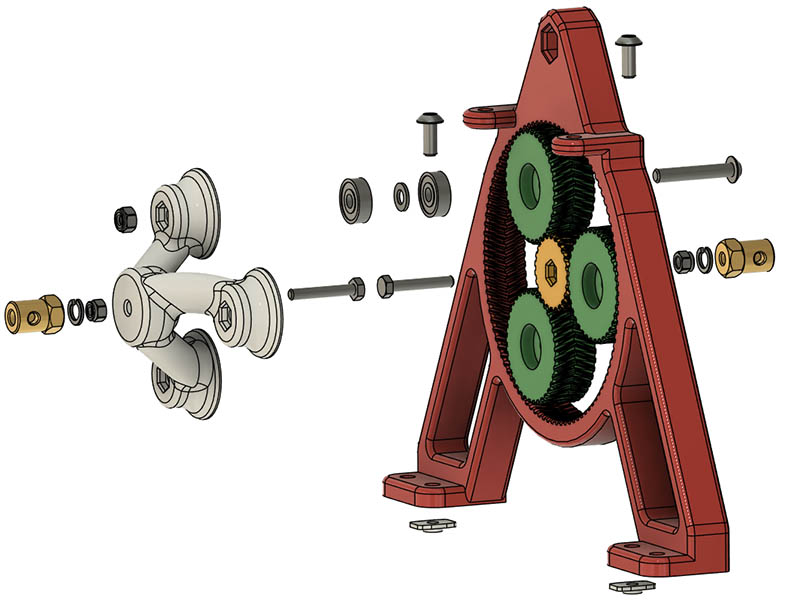
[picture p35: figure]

Insert a M4x25mm tap bolt through the bottom of the PlanetDrive_5_1_Rev35.stl shown in white, Tighten M4 Locknut down on top of Planet drive and add a lock washer on top then thread the brass hex coupler down tight.

Insert the other M4x25mm tap bolt through the top of the sun shown in yellow. Before adding all that hardware, we want to add all the planet bearings as it will be easier. Add the 3 – M5x35mm screws (30mm length might work) through the bottom of each planet. While holding them in place with your fingers, place this gear system on a flat surface. Put a 625-2RS inside the top of each planet followed by M5 shim washer and bearing. I included M5_Bearing_Shims.stl you can probably use in place of the M5 shim washers. Place the PlanetDrive_5_1_Rev35.stl on top of the bearings. The M5x30mm screws should protrude through the top. Add a M5 locknut to each and tighten them all the way down, then loosen each M5x30mm screw a little until the gear system turns good. If you had put the M4 hardware on before this, you would not have been able to lay this planetary gear on a flat surface. Now add a M4 locknut down tight on the bottom of the sun and add a lock washer followed by the other brass hex coupler. Tighten the hex coupler all the way down. The M5 end of the coupler behind the sun gear connects to the motor and the other one connects to the shaft. The 2-M5x12mm screws and Tee Nuts connect this planetary gear to the top of the 2040 extrusion.

Nema 17 Motor Mount Assembly

Hardware:

Nema 17 connection hardware:

1 – Nema 17 motor (Mine is a 0.9 degree 40mm deep specified in BOM)

4 – M3x10mm screws

2040 Connection hardware:

2 – M5x12mm screws

2 – M5 Tee Nuts

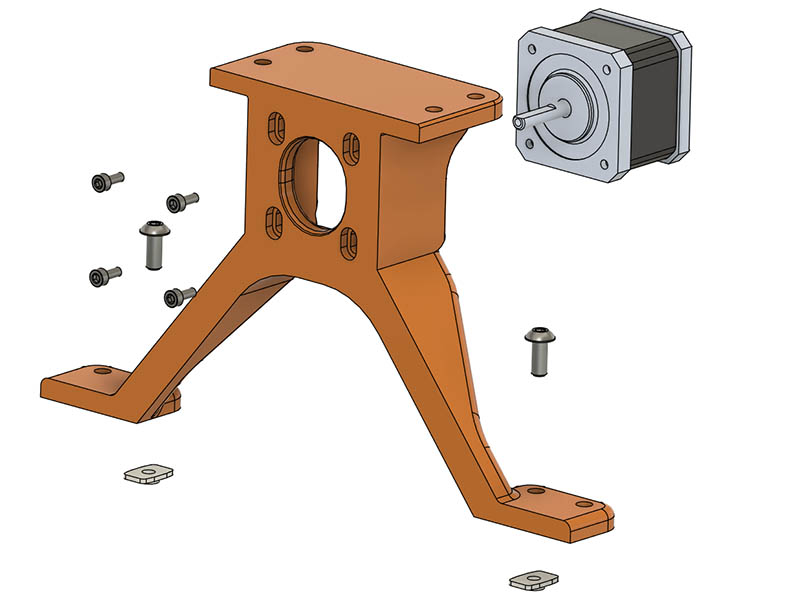
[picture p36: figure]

Wobble Disc Assembly with shaft

If you cut your own disc out of stainless steel sheet, your hardware will be different. Whatever method you use, I would recommend 3d printing WobbleDisck_Mount_JamNuts.stl out of PLA first to check the diameter size. Print it on a 45 degree angle and add manual tree support between bottom and mid-section. My disc ended up being about 5.14” or 130.175mm which is the size of that .stl file.

Hardware:

1 – 316L 3D Printed Stainless Steel Wobble disc

1 – M5x200mm fully threaded 18-8 stainless steel shaft (18-8 = 304 SS)

2 – 18-8 Stainless Steel External Tooth Lock Washers

4 – Regular M5 hex nuts (4mm thick to better get wrench on)

4 – M5 Serrated Flange Lock Nuts.

2 – M5x10x18mm 18-8 Stainless Steel Spacers

Only the 2 external tooth lock washers, 2 hex nuts, and 2 serrated flange lock nuts are really necessary. I added the spacers with hex nut, flange nut to cover the threads more. Using more spacers will make it more difficult to put the shaft in. I also recommend drilling out the shaft openings with a 3/8” cobalt drill bit so the shaft does not ride on the sifter at all. That larger hole also allows you to thread all the hardware on outside the sifter. I left about 15mm of the shaft on the outside bearing side and 31mm on the drive side. The coupling on the drive shaft side has 2 set screws 180 degrees apart, so I also filed down the shaft on the drive side on 2 sides so coupling gets better grip.

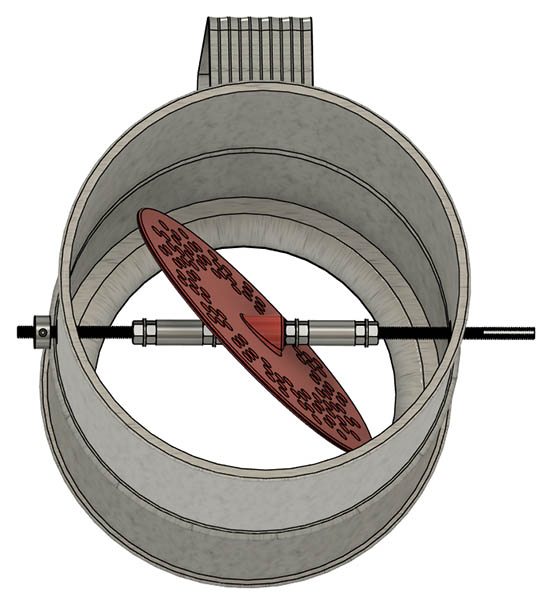
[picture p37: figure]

Mount Flour Sifter Assembly to Frame

Hardware:

1 – Assembly from previous procedure

1 - 5"-7" SS Band Clamp

4 – 18x18x30 L Brackets as shown in BOM

4 – M5x12mm screws

4 – Tee Nuts

12 - M5 fender washers as shown in BOM

Mount as shown in graphic below.

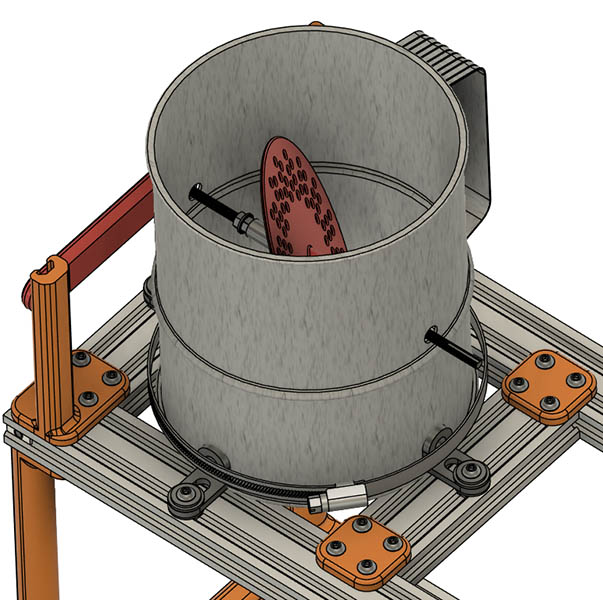
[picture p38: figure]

Mount Planetary gear assembly and Motor Mount Assembly

Hardware:

4 – M5x12mm screws

4 – Tee Nuts

Now add the planetary gear assembly and motor mount assembly. There are 2 extra mounting holes on both the planetary gear and motor mount, but since they are tied together I only use one screw on each side of the mount as shown.

To get the motor to correct height, use HexAdapter_Height_Shim.stl between the top of the 2040 extrusion and the bottom of a flat side of the hex coupler. Loosen the screws on the motor mount and adjust to fit on top of that shim. It will probably be center of the slot opening on the mount.

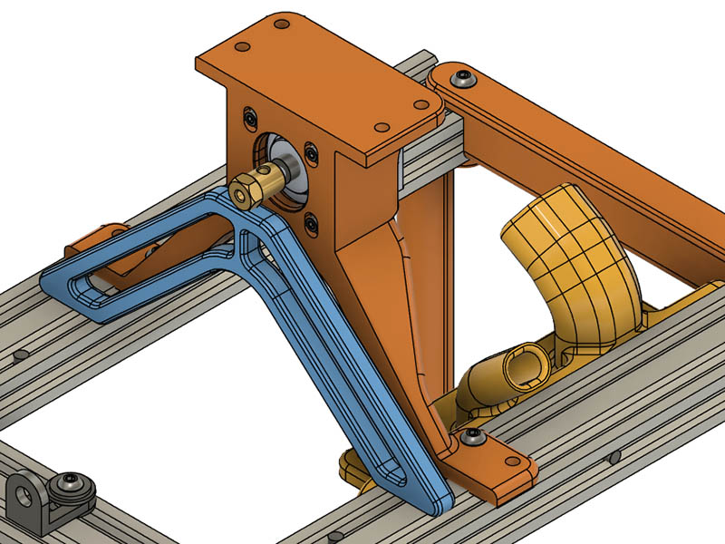
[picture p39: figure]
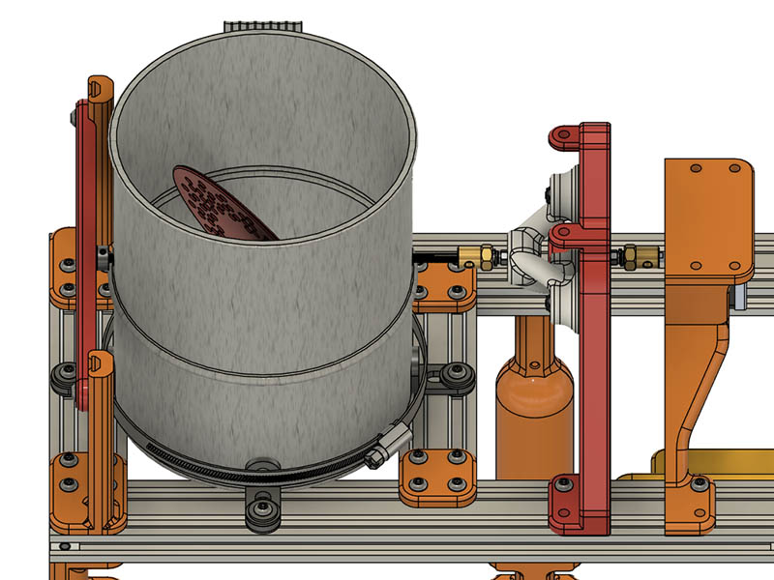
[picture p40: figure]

End Cap Assembly

4 – 3D printed End caps

8 – M5x12mm screws

8 – M5 Tee Nuts.

Add the End Caps as shown. They will be the same on both ends

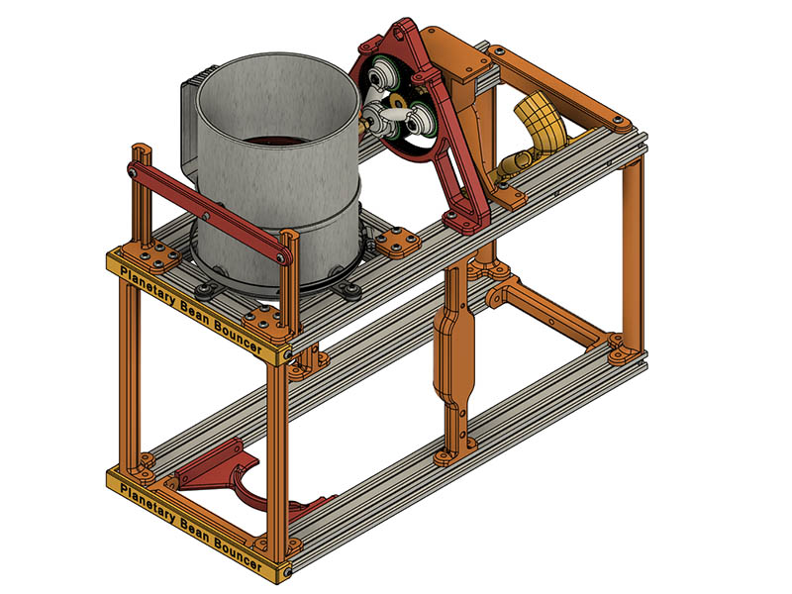
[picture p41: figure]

This completes the frame and mechanical build.

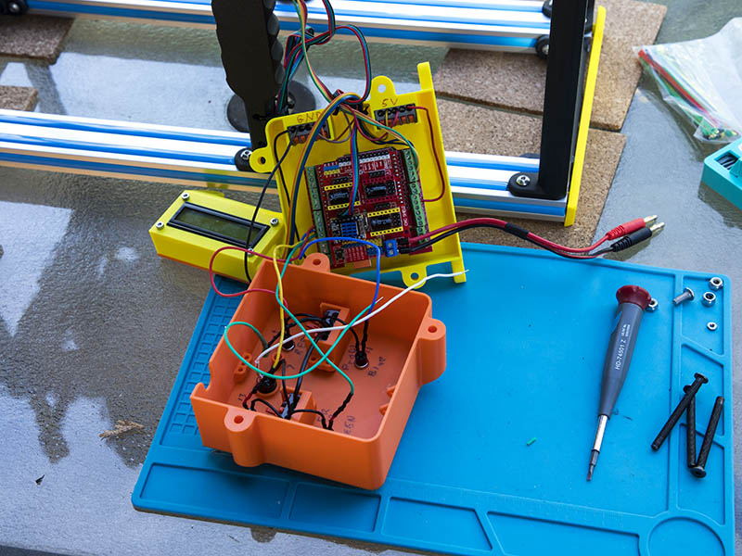
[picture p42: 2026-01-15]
media/photos/wiring_overview_IMG_5986.jpg

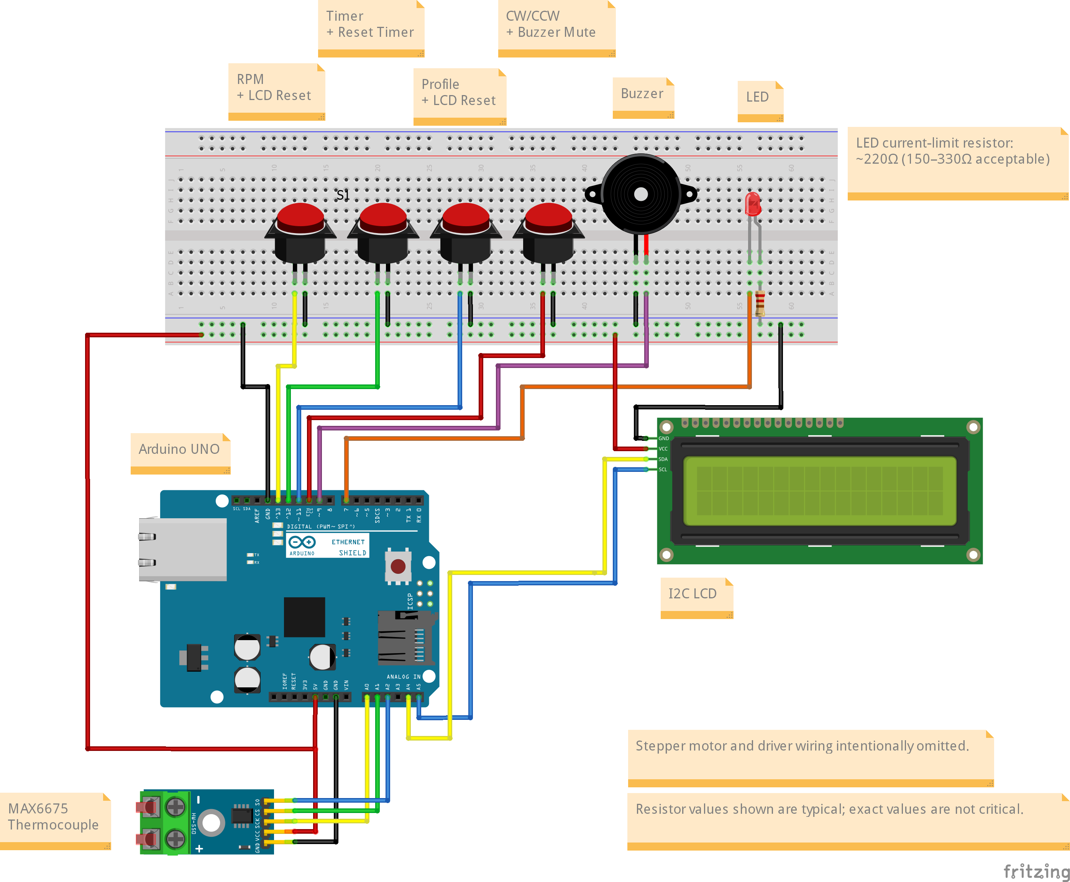
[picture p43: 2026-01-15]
wiring/Planetary_Bean_Bouncer_UI_bb.png

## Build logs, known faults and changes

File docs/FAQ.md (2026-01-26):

## FAQ

### Is this a beginner-friendly project?
No. This project is intended for experienced makers who are comfortable working with mechanical assemblies, electronics, and heat sources. It is shared as an experimental DIY design rather than a turnkey or beginner kit.

### Can I build this without the planetary gear or wobble disc?
Yes. The design is modular, and builders are encouraged to experiment. The wobble disc and planetary gear system are included to improve bean agitation, but alternative approaches are possible depending on your goals.

### What batch size does this support?
Batch size depends on the specific drum, motor, gearing, and configuration used. Small test batches are recommended during initial setup and tuning before attempting larger roasts.

### Is this food safe?
This is an experimental DIY project and is not food-safety certified. Components that contact the beans are designed to be made from stainless steel (typically 304 or 316L), which are commonly considered food-safe materials. However, no guarantees are made, and builders are responsible for material selection, cleanliness, and safe operation.

### Why are the electronics, firmware, and build instructions not included here?
To keep versioning and documentation manageable, firmware, electronics, and detailed build instructions are maintained in the GitHub repository rather than distributed with the STL files. Refer to the main project documentation before building.

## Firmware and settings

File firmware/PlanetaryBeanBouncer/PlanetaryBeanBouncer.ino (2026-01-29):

/*
 ===============================
  Planetary Bean Bouncer Firmware
 ===============================

 Version:       v0.1.1
 Release date:  2026-01-26
 Author:        David Bunch
 License:       MIT (firmware) / CC-BY-NC (hardware)
 Repository:    https://github.com/geodave810/planetary-bean-bouncer
 Description:   DIY coffee roaster controller using a single-motor flour sifter
*/

// ==============================
// Firmware Version
// ==============================
#define FW_NAME        "Planetary Bean Bouncer"
#define FW_VERSION     "v0.1.1"

#include <Wire.h>
#include <LiquidCrystal_I2C.h>
#include <max6675.h>   // Thermocouple module (MAX6675)

// ==============================
// LCD setup
// ==============================
LiquidCrystal_I2C lcd(0x27, 16, 2);

// ==============================
// Stepper / TMC2209 (X slot on CNC shield)
// ==============================
#define STEP_PIN 2
#define DIR_PIN  5
#define EN_PIN   8

#define FULL_STEPS_PER_REV 400.0 // 0.9 Degree Motor
#define MICROSTEPS         8.0   // 1/8 step

#define SHOW_STARTUP_BANNER 1
#define BANNER_TIME_MS 3000

bool showingBanner = SHOW_STARTUP_BANNER;
unsigned long bannerStartTime = 0;
// ==============================
// Buttons (active LOW, INPUT_PULLUP)
// ==============================
#define BTN_MOTOR    10   // CW/CCW toggle + long-press Buzzer Mute
#define BTN_PROFILE  11   // Change to different RPM range + long-press (LCD reset)
#define BTN_TIMER    12   // start/stop + long-press reset timer to 0
#define BTN_RPM      13   // Change to different RPM in current set array + long-press to toggle F/C

// ==============================
// Single status LED + buzzer
// ==============================
#define LED_STATUS   7
#define BUZZER_PIN   9    // active buzzer on D9 (tone() is non-blocking)

// ==============================
// Thermocouple #1 pins (use A0/A1/A2 as DIGITAL pins)
// SCK/CLK = output, CS = output, SO/DO = input
// ==============================
#define TC1_SCK  A0
#define TC1_CS   A1
#define TC1_SO   A2

MAX6675 tc1(TC1_SCK, TC1_CS, TC1_SO);

// ==============================
// Thermocouple #2 pins (FUTURE, commented out)
// ==============================
// #define TC2_SCK  3
// #define TC2_CS   4
// #define TC2_SO   6
// MAX6675 tc2(TC2_SCK, TC2_CS, TC2_SO);

// ==============================
// TEMP ALERTS (Fahrenheit thresholds)
// ==============================
float TEMP_BEEP_2F = 250.0;   // double beep
float TEMP_BEEP_3F = 275.0;   // triple beep
float TEMP_REARM_HYST_F = 5.0;  // must cool this much below threshold to re-arm

// ==============================
// Thermocouple calibration
// ==============================
// Positive value = TC reads low, Negative = TC reads high
// Your TC reads ~4°F high → subtract 4°F
//const float TC1_OFFSET_F = -4.0;  // Mine temperature shows about 4 degrees too high, so I use -4.0
const float TC1_OFFSET_F = 0.0;

unsigned long lastTempSampleMs = 0;
const unsigned long TEMP_SAMPLE_MS = 200; // 5 Hz (adjust 100–500ms)
float lastTempF = NAN;

// ==============================
// Buzzer pattern timing
// ==============================
uint16_t BEEP_FREQ_HZ = 2400;   // tone frequency
uint16_t BEEP_ON_MS   = 80;
uint16_t BEEP_OFF_MS  = 90;

// Set to 1 if you want tone(), 0 if you just switch an "active buzzer" HIGH/LOW
#define USE_TONE 1

// ==============================
// RPM Profiles
// ==============================
#define NUM_PROFILES 4
#define NUM_PRESETS  6
//
// Speed tops out at 240rpm for me, so I set that at maximum
// Profile P0 is for 1:1 ratio which starts at 15 rpm
// Profile P1 is for 4:1 ratio which starts with 60 rpm and 15 rpm at the wobble disc
// Profile P2 is for 5:1 ratio which starts with 75 rpm and 15 rpm at the wobble disc (This is what I am using)
int profiles[NUM_PROFILES][NUM_PRESETS] = {
  { 15,  20,  30,  40,  50,  60 },
  { 60,  80, 120, 160, 200, 240 },
  { 75, 100, 150, 200, 220, 240 },
  { 90,  120, 180, 200, 220, 240 }
};
int currentProfile = 2;  // Range 0 - 3 since NUM_PROFILES = 4
int currentPreset  = 2;  // Range 0 - 5 since NUM_PRESETS = 6

bool tempUnitsF = true;  // true=F, false=C

// RPM long-press
bool rpmBtnPrev = false;
bool rpmLongFired = false;
unsigned long rpmHoldStartMs = 0;
const unsigned long RPM_LONG_MS = 1200;  // hold to toggle F/C

// PROFILE long-press (LCD reset)
bool profileBtnPrev = false;
bool profileLongFired = false;
unsigned long profileHoldStartMs = 0;
const unsigned long PROFILE_LONG_MS = 1500;

// ==============================
// Motor state / step timing
// ==============================
bool motorEnabled = true;           // driver enabled
bool motorDirectionCCW = false;     // true=CCW (DIR LOW), false=CW (DIR HIGH)

bool beepsEnabled = true;

// Motor button long-press (Beep On/Off for possible quiet mode)
bool motorBtnPrev = false;
bool motorLongFired = false;
unsigned long motorHoldStartMs = 0;
const unsigned long MOTOR_LONG_MS = 1500;  // 1.5s

unsigned long stepDelayMicros = 0;
unsigned long lastStepMicros  = 0;

// ==============================
// Timer state
// ==============================
bool timerRunning          = false;
unsigned long roastSeconds = 0;
unsigned long lastTickMs   = 0;

// Beep tracking (minute / 10-min beeps)
unsigned long lastMinuteBeepSec = 0;
int           lastTenMinBeepMin = 0;

// Timer button long-press
bool timerBtnPrev              = false;
bool timerLongFired            = false;
unsigned long timerHoldStartMs = 0;
const unsigned long TIMER_LONG_MS = 1500;  // hold to reset

// Other button edge tracking
bool lastMotorPressed   = false;

const unsigned long DEBOUNCE_MS = 35;  // try 35–60ms if needed

struct DebounceBtn {
  uint8_t pin;
  bool stable;          // debounced state: true = pressed
  bool lastRaw;
  unsigned long lastChangeMs;
};

DebounceBtn dbMotor   = { BTN_MOTOR,   false, false, 0 };
DebounceBtn dbProfile = { BTN_PROFILE, false, false, 0 };
DebounceBtn dbTimer   = { BTN_TIMER,   false, false, 0 };
DebounceBtn dbRpm     = { BTN_RPM,     false, false, 0 };

bool readPressedRaw(uint8_t pin) {
  return digitalRead(pin) == LOW;   // active LOW buttons
}

bool debounceRead(DebounceBtn &b) {
  bool raw = readPressedRaw(b.pin);

  if (raw != b.lastRaw) {
    b.lastRaw = raw;
    b.lastChangeMs = millis();
  }

  if ((millis() - b.lastChangeMs) >= DEBOUNCE_MS) {
    b.stable = raw;
  }

  return b.stable; // true = pressed
}

// ==============================
// BEEP PATTERN (non-blocking)
// ==============================
static uint8_t  beepRemaining = 0;
static bool     beepIsOn = false;
static uint32_t beepNextMs = 0;

void startBeepPattern(uint8_t count) {
  // Don’t interrupt an in-progress pattern
  if (!beepsEnabled) return;
  if (beepRemaining > 0) return;
  beepRemaining = count;
  beepIsOn = false;
  beepNextMs = 0;
}

void serviceBeepPattern(uint8_t buzzerPin) {
  if (beepRemaining == 0) return;

  uint32_t now = millis();
  if (beepNextMs != 0 && (int32_t)(now - beepNextMs) < 0) return;

  if (!beepIsOn) {
#if USE_TONE
    tone(buzzerPin, BEEP_FREQ_HZ);
#else
    digitalWrite(buzzerPin, HIGH);
#endif
    beepIsOn = true;
    beepNextMs = now + BEEP_ON_MS;
  } else {
#if USE_TONE
    noTone(buzzerPin);
#else
    digitalWrite(buzzerPin, LOW);
#endif
    beepIsOn = false;
    beepRemaining--;
    beepNextMs = now + BEEP_OFF_MS;
  }
}

// Threshold one-shot logic
static bool beep2F_armed = true;
static bool beep3F_armed = true;

// tempF must be Fahrenheit here
void checkTempAlertsF(float tempF, uint8_t buzzerPin) {
  if (beep2F_armed && tempF >= TEMP_BEEP_2F) {
    startBeepPattern(2); // double beep
    beep2F_armed = false;
  }
  if (beep3F_armed && tempF >= TEMP_BEEP_3F) {
    startBeepPattern(3); // triple beep
    beep3F_armed = false;
  }

  // Re-arm only after cooling below threshold (hysteresis)
  if (!beep2F_armed && tempF <= (TEMP_BEEP_2F - TEMP_REARM_HYST_F)) beep2F_armed = true;
  if (!beep3F_armed && tempF <= (TEMP_BEEP_3F - TEMP_REARM_HYST_F)) beep3F_armed = true;

  serviceBeepPattern(buzzerPin);
}

bool isBeepPatternActive() {
  return beepRemaining > 0;
}

// ==============================
// Helpers
// ==============================
unsigned long rpmToDelayMicros(int rpm) {
  float stepsPerRev    = FULL_STEPS_PER_REV * MICROSTEPS; // 400 * 8 = 3200
  float stepsPerSecond = (rpm * stepsPerRev) / 60.0;
  return (unsigned long)(1000000.0 / stepsPerSecond);
}

// ==============================
// Buzzer helpers (tone duration is non-blocking)
// ==============================
// 80ms
void beepShort() {
  if (!beepsEnabled) return;
  tone(BUZZER_PIN, 2000, 80);
}
// 300ms
void beepLong() {
  if (!beepsEnabled) return;
  tone(BUZZER_PIN, 1500, 300);
}
// 200ms
void confirmBeep() {
  if (!beepsEnabled) return;
  tone(BUZZER_PIN, 1800, 200);
}

inline float applyTC1Offset(float value, bool isFahrenheit) {
  if (isFahrenheit) {
    return value + TC1_OFFSET_F;
  } else {
    return value + (TC1_OFFSET_F * 5.0 / 9.0);
  }
}

// ==============================
// Thermocouple reading
// ==============================
// Read TC1 in Fahrenheit (for alerts). Returns NAN if not valid.
float readTC1_F() {
  double c = tc1.readCelsius();
  if (isnan(c)) return NAN;

  float f = (c * 9.0 / 5.0) + 32.0;
  return applyTC1Offset(f, true);
}

// Read TC1 in current display units for LCD (int). -999 = invalid
int readTC1_displayUnits() {
  double c = tc1.readCelsius();
  if (isnan(c)) return -999;

  if (tempUnitsF) {
    float f = (c * 9.0 / 5.0) + 32.0;
    f = applyTC1Offset(f, true);
    return (int)(f + 0.5);
  } else {
    float cf = applyTC1Offset((float)c, false);
    return (int)(cf + 0.5);
  }
}

// ==============================
// LCD update (NO lcd.clear(); overwrite full lines)
// Line 1: P# R### Tmm:ss RUN/STOP
// Line 2: TC1:###F CCW/CW
// ==============================
void updateLCD() {
  char line0[17];
  char line1[17];

  int rpm  = profiles[currentProfile][currentPreset];
  int mins = roastSeconds / 60;
  int secs = roastSeconds % 60;

  // Line 0
  snprintf(line0, sizeof(line0), "P%d R%d T%02d:%02d %s",
           currentProfile, rpm, mins, secs, timerRunning ? "RUN" : "STP");
  int len0 = strlen(line0);
  for (int i = len0; i < 16; i++) line0[i] = ' ';
  line0[16] = '\0';

  // Line 1
  int t = readTC1_displayUnits();
  char unitChar = tempUnitsF ? 'F' : 'C';

const char* dirStr = motorDirectionCCW ? "CCW" : "CW ";
const char  muteChar = beepsEnabled ? ' ' : 'M';  // M = muted

if (t == -999) {
  snprintf(line1, sizeof(line1),
           "TC1:---%c %s%c",
           unitChar, dirStr, muteChar);
} else {
  snprintf(line1, sizeof(line1),
           "TC1:%3d%c %s%c",
           t, unitChar, dirStr, muteChar);
}


  int len1 = strlen(line1);
  for (int i = len1; i < 16; i++) line1[i] = ' ';
  line1[16] = '\0';

  lcd.setCursor(0, 0);
  lcd.print(line0);
  lcd.setCursor(0, 1);
  lcd.print(line1);
}

// ==============================
// LCD soft reset
// ==============================
void resetLCDSoft() {
  Wire.begin();
  Wire.setClock(100000);

  delay(20);
  lcd.init();
  lcd.backlight();
  lcd.clear();
  delay(10);
  updateLCD();
  confirmBeep();
}

// ==============================
// Setup
// ==============================
void setup() {
  lcd.init();
  lcd.backlight();

  updateLCD();

  #if SHOW_STARTUP_BANNER
    lcd.clear();
    lcd.setCursor(0, 0);
    lcd.print(FW_NAME);
    lcd.setCursor(0, 1);
    lcd.print(FW_VERSION);

    bannerStartTime = millis();
  #endif

  // Stepper pins
  pinMode(STEP_PIN, OUTPUT);
  pinMode(DIR_PIN,  OUTPUT);
  pinMode(EN_PIN,   OUTPUT);

  // Default direction
  motorDirectionCCW = false;
  digitalWrite(DIR_PIN, LOW);

  // Enable driver (LOW active on CNC shield)
  motorEnabled = true;
  digitalWrite(EN_PIN, motorEnabled ? LOW : HIGH);

  // Buttons
  pinMode(BTN_MOTOR,   INPUT_PULLUP);
  pinMode(BTN_RPM,     INPUT_PULLUP);
  pinMode(BTN_PROFILE, INPUT_PULLUP);
  pinMode(BTN_TIMER,   INPUT_PULLUP);

  // Status LED + buzzer
  pinMode(LED_STATUS, OUTPUT);
  digitalWrite(LED_STATUS, LOW);

  pinMode(BUZZER_PIN, OUTPUT);
  digitalWrite(BUZZER_PIN, LOW);

  // Initial RPM
  int startRPM = profiles[currentProfile][currentPreset];
  stepDelayMicros = rpmToDelayMicros(startRPM);

  // MAX6675 needs a brief settling time
  delay(250);

}

// ==============================
// Buttons
// ==============================

// Motor button: toggle CW/CCW
void handleMotorButton(bool pressed) {
  unsigned long now = millis();

  // Just pressed
  if (pressed && !motorBtnPrev) {
    motorHoldStartMs = now;
    motorLongFired = false;
  }

  // Long press → toggle beeps ON/OFF
  if (pressed && !motorLongFired && (now - motorHoldStartMs) >= MOTOR_LONG_MS) {
    beepsEnabled = !beepsEnabled;
    motorLongFired = true;

    // Feedback
    if (beepsEnabled) {
      tone(BUZZER_PIN, 2000, 120);   // short confirm beep
    } else {
      tone(BUZZER_PIN, 1200, 300);   // lower / longer = "muted"
    }

    updateLCD();   // <-- add this so M updates immediately
  }

  // Short press → toggle CW/CCW
  if (!pressed && motorBtnPrev) {
    if (!motorLongFired) {
      motorDirectionCCW = !motorDirectionCCW;
      digitalWrite(DIR_PIN, motorDirectionCCW ? LOW : HIGH);
      updateLCD();
    }
  }

  motorBtnPrev = pressed;
}


// RPM button:
//  - Short press: Change RPM in current Profile
//  - Long press: Toggle F/C
void handleRpmButton(bool pressed) {
  unsigned long now = millis();

  // Just pressed
  if (pressed && !rpmBtnPrev) {
    rpmHoldStartMs = now;
    rpmLongFired = false;
  }

  // Held long enough -> toggle F/C (fires once)
  if (pressed && !rpmLongFired && (now - rpmHoldStartMs) >= RPM_LONG_MS) {
    tempUnitsF = !tempUnitsF;
    rpmLongFired = true;
    confirmBeep();
    updateLCD();
  }

  // Just released
  if (!pressed && rpmBtnPrev) {
    if (!rpmLongFired) {
      currentPreset++;
      if (currentPreset >= NUM_PRESETS) currentPreset = 0;

      int rpm = profiles[currentProfile][currentPreset];
      stepDelayMicros = rpmToDelayMicros(rpm);
      updateLCD();
    }
  }

  rpmBtnPrev = pressed;
}

// Profile button: cycle profile, long press LCD reset
void handleProfileButton(bool pressed) {
  unsigned long now = millis();

  // Just pressed
  if (pressed && !profileBtnPrev) {
    profileHoldStartMs = now;
    profileLongFired = false;
  }

  // Held long enough -> LCD soft reset
  if (pressed && !profileLongFired && (now - profileHoldStartMs) >= PROFILE_LONG_MS) {
    profileLongFired = true;
    resetLCDSoft();
  }

  // Just released
  if (!pressed && profileBtnPrev) {
    if (!profileLongFired) {
      currentProfile++;
      if (currentProfile >= NUM_PROFILES) currentProfile = 0;

      int rpm = profiles[currentProfile][currentPreset];
      stepDelayMicros = rpmToDelayMicros(rpm);
      updateLCD();
    }
  }

  profileBtnPrev = pressed;
}

// Timer button:
//  - Short press: toggle start/stop
//  - Long press: reset + confirm beep
void handleTimerButton(bool pressed) {
  unsigned long now = millis();

  // Just pressed
  if (pressed && !timerBtnPrev) {
    timerHoldStartMs = now;
    timerLongFired = false;
  }

  // Long press reset
  if (pressed && !timerLongFired && (now - timerHoldStartMs) >= TIMER_LONG_MS) {
    timerRunning = false;
    roastSeconds = 0;
    lastMinuteBeepSec = 0;
    lastTenMinBeepMin = 0;
    timerLongFired = true;
    confirmBeep();
    updateLCD();
  }

  // Just released
  if (!pressed && timerBtnPrev) {
    if (!timerLongFired) {
      timerRunning = !timerRunning;
      if (timerRunning) {
        lastTickMs = millis();
        lastMinuteBeepSec = 0;
        lastTenMinBeepMin = 0;
      }
      updateLCD();
    }
  }

  timerBtnPrev = pressed;
}

// ==============================
// Timer tick + beeps + status LED
// ==============================
void handleTimerTickAndStatusLED() {
  static bool ledState = false;

  if (!timerRunning) {
    if (ledState) {
      ledState = false;
      digitalWrite(LED_STATUS, LOW);
    }
    return;
  }

  unsigned long now = millis();

  if (now - lastTickMs >= 1000) {
    lastTickMs += 1000;
    roastSeconds++;

    // Blink LED each second
    ledState = !ledState;
    digitalWrite(LED_STATUS, ledState ? HIGH : LOW);

    int mins = roastSeconds / 60;
    int secs = roastSeconds % 60;

    // Avoid colliding with temp alert beeps if you want
    bool okToBeep = !isBeepPatternActive();

    // Short beep every full minute (except t=0)
    if (okToBeep && secs == 0 && roastSeconds > 0 && roastSeconds != lastMinuteBeepSec) {
      beepShort();
      lastMinuteBeepSec = roastSeconds;
    }

    // Long beep every 10 minutes
    if (okToBeep && secs == 0 && mins > 0 && (mins % 10) == 0 && mins != lastTenMinBeepMin) {
      beepLong();
      lastTenMinBeepMin = mins;
    }

    updateLCD();
  }
}

// ==============================
// Stepper motion (non-blocking)
// ==============================
void handleStepper() {
  if (!motorEnabled) return;

  unsigned long nowMicros = micros();
  if (nowMicros - lastStepMicros >= stepDelayMicros) {
    lastStepMicros = nowMicros;
    digitalWrite(STEP_PIN, HIGH);
    digitalWrite(STEP_PIN, LOW);
  }
}

// ==============================
// Main loop
// ==============================
void loop() {

#if SHOW_STARTUP_BANNER
  if (showingBanner) {
    if (millis() - bannerStartTime >= BANNER_TIME_MS) {
      showingBanner = false;
      lcd.clear();

      updateLCD();          // <-- force an immediate redraw
      // lastLcdUpdate = 0;  // <-- optional: reset your LCD refresh timer variable if you have one
    } else {
      return;
    }

  }
#endif

  bool motorPressed   = debounceRead(dbMotor);
  bool rpmPressed     = debounceRead(dbRpm);
  bool profilePressed = debounceRead(dbProfile);
  bool timerPressed   = debounceRead(dbTimer);

  handleMotorButton(motorPressed);
  handleRpmButton(rpmPressed);
  handleProfileButton(profilePressed);
  handleTimerButton(timerPressed);

// Temperature alerts (sample TC at a sane rate; still service beep engine every loop)
unsigned long now = millis();
if (now - lastTempSampleMs >= TEMP_SAMPLE_MS) {
  lastTempSampleMs = now;
  lastTempF = readTC1_F(); // read MAX6675 only 5x/sec
}

if (!isnan(lastTempF)) {
  checkTempAlertsF(lastTempF, BUZZER_PIN);
} else {
  serviceBeepPattern(BUZZER_PIN);
}


  handleTimerTickAndStatusLED();
  handleStepper();
}

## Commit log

2026-01-17 Add mechanical build guide and correct BOM omissions
    [Planetary_Bean_Bouncer_BOM.xlsx]
2026-01-18 Updated drill guide STL file and BOM
    [Planetary_Bean_Bouncer_BOM.xlsx, SilfterOutsideDrillGuide.stl]
2026-01-26 Small changes to tidy of electrical
    [ArduioUnoBaseMount_Rev4.stl, ArduioUnoBaseMount_Rev4_1.stl, ArduioUnoMount_Rev4.3mf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]
2026-01-26 Correction to Arduiono Base Mount
    [ArduioUnoBaseMount_Rev4_1.stl, ArduioUnoMount_Rev4.3mf]
2026-01-26 Update arduino Uno Base
    [ArduioUnoBaseMount_Rev4_1.stl, ArduioUnoMount_Rev4.3mf]
2026-01-28 Updated Build guide and some STL files
    [Bearing_Height_Shim.stl, FlourPlanetGears_5_1_24_36_96_Rev35.stl, Gearing_5_1_16_24_64_Test_Rev36.3mf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]
2026-01-28 Added Test print image
2026-01-28 Adjusted README and buildguide
    [Gearing_5_1_16_24_64_Test_Rev36.3mf]
2026-01-29 Minor Changes before release
    [M5_Bearing_Shims.stl]
2026-11-04 1st ESP32 version Upload
    1st ESP32 version Upload
2026-11-04 Add 3 KiCad Images
2026-11-04 Updat BOM
